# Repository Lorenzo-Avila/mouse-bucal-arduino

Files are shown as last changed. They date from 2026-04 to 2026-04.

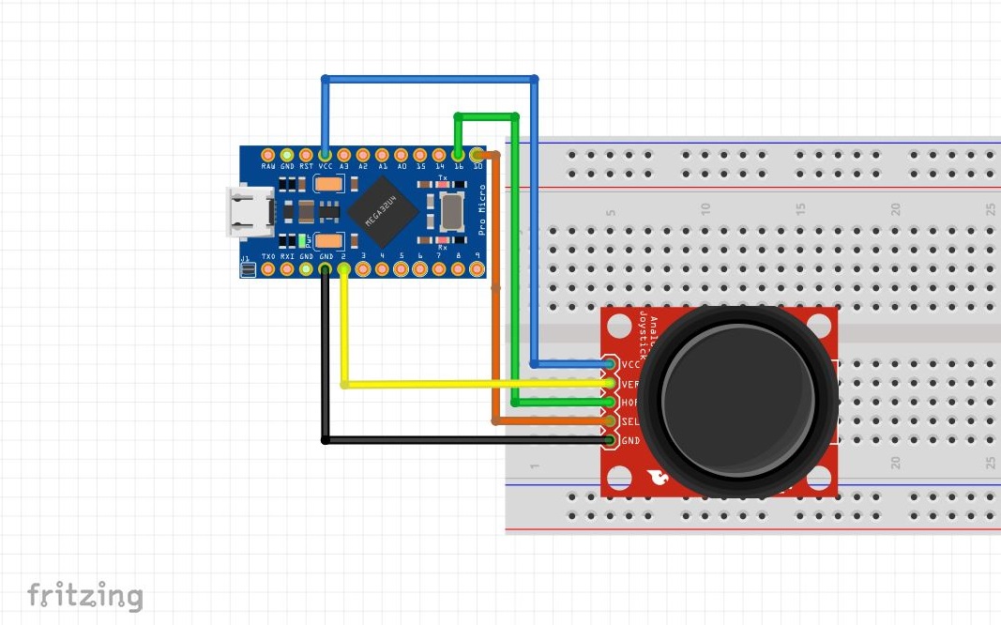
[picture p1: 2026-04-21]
hardware/Diagrama_de_Circuitos.JPG

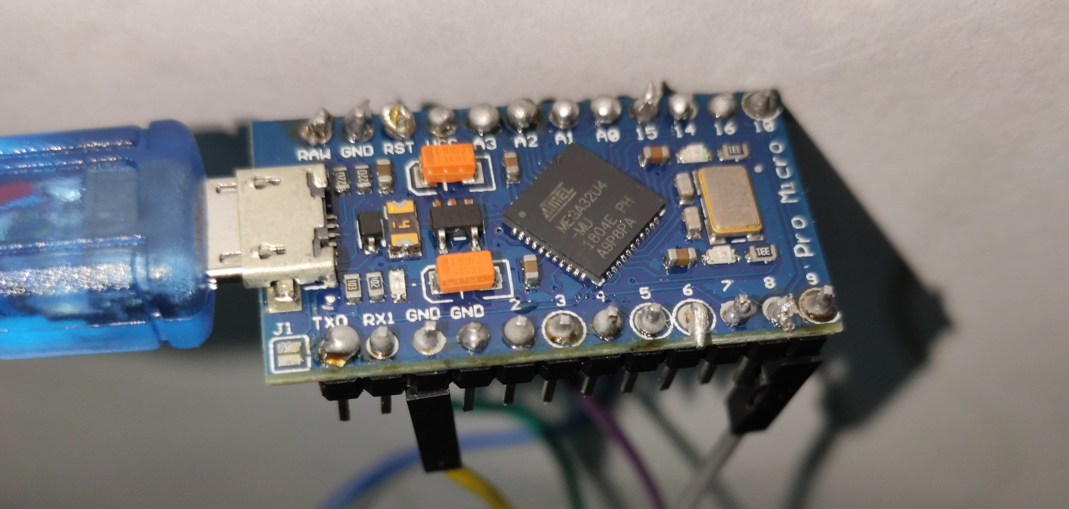
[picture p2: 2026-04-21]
fotos_prototipo/Ligacoes_2.jpg

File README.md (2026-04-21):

# 🖱️ Mouse Bucal — Tecnologia Assistiva com Arduino Pro Micro

> **TCC — Instituto Federal de Educação, Ciência e Tecnologia Farroupilha Campus São Borja — Técnico em Informática (2020)**  
> Dispositivo de interface humana (HID) que emula um mouse via joystick controlado pela boca, projetado para pessoas com deficiências motoras severas nos membros superiores.

---

## 📋 Sumário

- [Problema Resolvido](#-problema-resolvido)
- [Como Funciona](#-como-funciona)
- [Tecnologias e Componentes](#-tecnologias-e-componentes)
- [Estrutura do Repositório](#-estrutura-do-repositório)
- [Instalação e Montagem](#-instalação-e-montagem)
- [Configuração do Software](#-configuração-do-software)
- [Diagrama de Atores e Fluxo](#-diagrama-de-atores-e-fluxo)
- [Análise Técnica do Código](#-análise-técnica-do-código)
- [Modelo 3D](#-modelo-3d)
- [Sugestões de Melhorias](#-sugestões-de-melhorias)
- [Fundamentação Teórica](#-fundamentação-teórica)

---

## 🎯 Problema Resolvido

Pessoas com limitações motoras severas nos membros superiores como tetraplegia, distrofia muscular ou sequelas de AVC encontram barreiras significativas no uso de computadores convencionais. Este projeto oferece uma solução de **Tecnologia Assistiva (TA)** de baixo custo que permite controle completo do cursor por meio de movimentos da boca/cabeça, promovendo autonomia digital e inclusão social.

**Contexto:** A Declaração de Salamanca (1994) e as diretrizes brasileiras de inclusão exigem ferramentas adaptadas para que pessoas com deficiência possam participar plenamente de atividades educacionais e profissionais mediadas por computador.

---

## ⚙️ Como Funciona

```
[Usuário]
    │
    ▼ movimento da boca/mandíbula
[Joystick 3 eixos]  ──(A0, A2, D9)──►  [Arduino Pro Micro]
                                               │
                                         USB HID (nativo)
                                               │
                                               ▼
                                        [Computador — Driver-free]
                                        Cursor X/Y + Click esquerdo
```

1. O joystick é posicionado na boca do usuário via suporte impresso em 3D.  
2. Movimentos da mandíbula/língua deflectem o joystick nos eixos X e Y.  
3. O Arduino Pro Micro lê os valores analógicos (ADC 10-bit, 0–1023).  
4. A diferença do valor neutro (calibrado na inicialização) é mapeada em deslocamento do cursor.  
5. Pressionar o joystick (eixo Z) aciona o clique esquerdo do mouse.  
6. O computador reconhece o dispositivo automaticamente como mouse USB (sem drivers adicionais).

---

## 🔧 Tecnologias e Componentes

### Hardware

| Componente | Especificação | Função |
|---|---|---|
| **Arduino Pro Micro** | ATmega32U4, 5V/16MHz | MCU com USB HID nativo |
| **Módulo Joystick** | 3 eixos (X, Y, Z), potenciômetros 10kΩ | Sensor de movimento |
| **Cabo USB Micro-B** | Standard | Alimentação + dados |
| **Invólucro 3D** | PLA/ABS, STL binário (51.518 triângulos) | Suporte ergonômico bucal |
| **Parafusos/Fixadores** | M2/M3 | Montagem mecânica |

### Software / Ferramentas

| Ferramenta | Versão Recomendada | Uso |
|---|---|---|
| **Arduino IDE** | 2.x | Upload do firmware |
| **Biblioteca `Mouse.h`** | Built-in (Arduino AVR) | Emulação HID USB |
| **Fritzing** | 0.9.x | Esquemático do circuito (`.fzz`) |
| **Slicer 3D** (Cura/PrusaSlicer) | Qualquer | Impressão do modelo `.stl` |

---

## 📁 Estrutura do Repositório

| Pasta | Arquivo(s) | Descrição |
|---|---|---|
| `firmware/` | `Emulador_Mouse.ino` | Código principal — lógica do mouse HID |
| `hardware/` | `Joystick_and_arduino.fzz` | Esquemático completo no Fritzing |
| | `esquematico_prototipo.JPG` | Diagrama de conexões (imagem) |
| | `esquema_de_funcionamento.png` | Fluxo do sistema |
| | `Diagrama_de_Circuitos.JPG` | Foto do circuito montado |
| `3dmodels[](url)/` | `Modelo3d_projeto.stl` | Invólucro bucal — STL binário (~2,5 MB, 51.518 triângulos) |
| `docs/` | `Ata_de_Defesa_Final_do_Trabalho_de_Conclusão_de_Curso.docx` | Ata de Defesa Final do Trabalho de Conclusão de Curso |
| `Relatório_de_Trabalho_de_Conclusao_de_curso.docx` | Relatório técnico  referente ao Trabalho de Conclusão de Curso |
| | `Atores_do_Sistema.jpg` | Diagrama de atores do sistema |
| `fotos_prototipo/` | `impressao_bucal_1.jpg` · `impressao_bucal_2.jpg`  | Vistas externas da impressão do bucal protótipo finalizado |
| | `protitpo_finalizado_sem_involtorio.jpg` · `prototipo_finalizado_com_involtorio_visao_externa.jpg` | Comparação sem/com invólucro |
| | `prototipo_finalizado_com_involtorio_parte_interna.jpg` | Eletrônica interna montada |
| | `Ligacoes_1.jpg` · `Ligacoes_2.jpg` · `Ligacoes_3.jpg` | Fiação e conexões detalhadas |
| | `arduino_pro_micro.jpg` · `Joystick.jpg` | Componentes individuais |

**Como abrir cada tipo de arquivo:**

| Extensão | Ferramenta |
|---|---|
| `.ino` | Arduino IDE 2.x |
| `.fzz` | Fritzing 0.9.x |
| `.stl` | Cura / PrusaSlicer / Blender |
| `.docx` | Word / LibreOffice Writer |
| `.jpg` / `.png` | Qualquer visualizador de imagens |

---

## 🔨 Instalação e Montagem

### Pré-requisitos

- Arduino IDE 2.x instalado
- Impressora 3D (ou serviço de impressão) para o invólucro
- Filamento PLA (recomendado para contato bucal: **PETG food-safe** ou revestimento com verniz atóxico)

### Passo 1 — Impressão 3D

1. Abra o arquivo `3d-models/Modelo 3d TCC (1).stl` no seu slicer.
2. Configurações sugeridas:
   - Preenchimento: **30–40%** (honeycomb)
   - Altura de camada: **0.2mm**
   - Suportes: Ativados (verifique as abas de encaixe do joystick)
3. Imprima e lixe as bordas que terão contato com a boca.

### Passo 2 — Conexões Elétricas

| Pino Joystick | Pino Arduino Pro Micro |
|---|---|
| VCC | VCC (5V) |
| GND | GND |
| VRX (eixo horizontal) | A0 |
| VRY (eixo vertical) | A2 |
| SW (botão/click) | D9 |

> **Atenção:** O pino D9 usa `INPUT_PULLUP` interno — leitura `LOW` indica botão pressionado.

### Passo 3 — Upload do Firmware

1. Abra `firmware/Emulador_Mouse.ino` na Arduino IDE.
2. Selecione: **Ferramentas → Placa → Arduino AVR → Arduino Leonardo** (compatível com Pro Micro ATmega32U4).
3. Selecione a porta COM correta.
4. Clique em **Upload**.
5. Na primeira inicialização, mantenha o joystick na **posição neutra** por 1 segundo — o código calibra o ponto zero automaticamente.

### Passo 4 — Montagem Mecânica

1. Encaixe o módulo joystick no suporte impresso.
2. Direcione os cabos pelo canal interno do invólucro.
3. Prenda o Arduino Pro Micro no compartimento traseiro.
4. Conecte o cabo USB ao computador — nenhum driver adicional necessário.

---

## 💻 Configuração do Software

### Ajuste de Sensibilidade

No arquivo `.ino`, a constante `sensitivity` controla a velocidade do cursor:

```cpp
const int sensitivity = 200; // ← altere este valor
```

| Valor | Comportamento |
|---|---|
| `50–100` | Cursor **muito rápido** — para usuários com controle preciso |
| `200` | **Padrão** (configuração original) |
| `400–600` | Cursor **lento** — ideal para tremores ou movimentos involuntários |

---

## 📐 Diagrama de Atores e Fluxo

**Atores do Sistema:**

- **Usuário** — pessoa com deficiência motora que utiliza o dispositivo bucal
- **Supervisor** — responsável pela instalação, posicionamento e verificação do protótipo

**Fluxo de Operação:**

```
Supervisor conecta USB → Sistema inicializa (1s calibração)
        │
        ├─ Sensores OK? ──NÃO──► Sistema reinicia
        │
        SIM
        │
        ▼
Monitoramento contínuo do joystick
        │
        ├─ Movimento eixo X → Mouse.move(Δx, 0, 0)
        ├─ Movimento eixo Y → Mouse.move(0, Δy, 0)
        └─ Botão pressionado → Mouse.press/release (LEFT)
```

---

## 🔬 Análise Técnica do Código

### Lógica Central

```cpp
// Leitura diferencial — desconta o ponto zero calibrado
vertValue = analogRead(vertPin) - vertZero;
horzValue = analogRead(horzPin) - horzZero;

// Movimento proporcional dividido pela sensibilidade
if (vertValue != 0) Mouse.move(0, vertValue / sensitivity, 0);
if (horzValue != 0) Mouse.move(horzValue / sensitivity, 0, 0);

// Clique com debounce via flag
if (digitalRead(selPin) == 0 && !mouseClickFlag) {
    mouseClickFlag = 1;
    Mouse.press(MOUSE_LEFT);
} else if (digitalRead(selPin) && mouseClickFlag) {
    mouseClickFlag = 0;
    Mouse.release(MOUSE_LEFT);
}
```

## 🖨️ Modelo 3D

- **Formato:** STL Binário
- **Complexidade:** 51.518 triângulos
- **Tamanho:** ~2,5 MB
- **Finalidade:** Invólucro ergonômico que acopla o módulo joystick em posição bucal
- **Integração com eletrônica:** Cavidades internas para passagem de cabos; compartimento traseiro para o Arduino Pro Micro; encaixe frontal para o joystick na posição bocal

> ⚠️ **Recomendação de material:** Para uso em contato com a boca, imprimir em **PETG food-safe** ou aplicar **revestimento atóxico** (verniz epóxi alimentar) sobre PLA.

### 🟢 Evoluções Futuras

**8. Sopro/Sucção como Botão** — sensor de pressão (BMP280) para ação de clique sem usar o joystick como botão

**9. Modo de Acessibilidade Configurável** — potenciômetro externo para ajuste de sensibilidade em tempo real sem reprogramar

**10. BLE/Wireless** — substituir Arduino Pro Micro por **Seeed XIAO nRF52840** para versão sem fio (Bluetooth HID)

**11. Controle por Inclinação (IMU)** — adicionar MPU-6050 para controle por movimento de cabeça, dispensando o joystick

---

## 📚 Fundamentação Teórica

- **Declaração de Salamanca (UNESCO, 1994):** Estabelece diretrizes mundiais para educação inclusiva, motivando o desenvolvimento de ferramentas assistivas.
- **Tecnologia Assistiva (TA):** Campo interdisciplinar que cria produtos e serviços para promover funcionalidade e autonomia de pessoas com deficiência.
- **USB HID (Human Interface Device):** Protocolo USB que permite que microcontroladores se comuniquem com computadores como periféricos de entrada sem drivers adicionais — viabilizado pelo chip ATmega32U4 do Arduino Pro Micro.
- **ADC (Analog-to-Digital Converter):** Converte o sinal analógico dos potenciômetros do joystick (0–5V) em valores digitais de 10 bits (0–1023), mapeados em deslocamento do cursor.

---

## 📄 Licença

Projeto acadêmico de código aberto. Uso livre para fins educacionais e de pesquisa em Tecnologia Assistiva.

---

*Desenvolvido como Trabalho de Conclusão de Curso — Técnico em Informática, 2020.*

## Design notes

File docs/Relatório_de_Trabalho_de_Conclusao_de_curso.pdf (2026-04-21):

INSTITUTO FEDERAL DE EDUCAÇÃO, CIÊNCIA E TECNOLOGIA FARROUPILHA CAMPUS SÃO BORJA
CURSO TÉCNICO EM INFORMÁTICA INTEGRADO

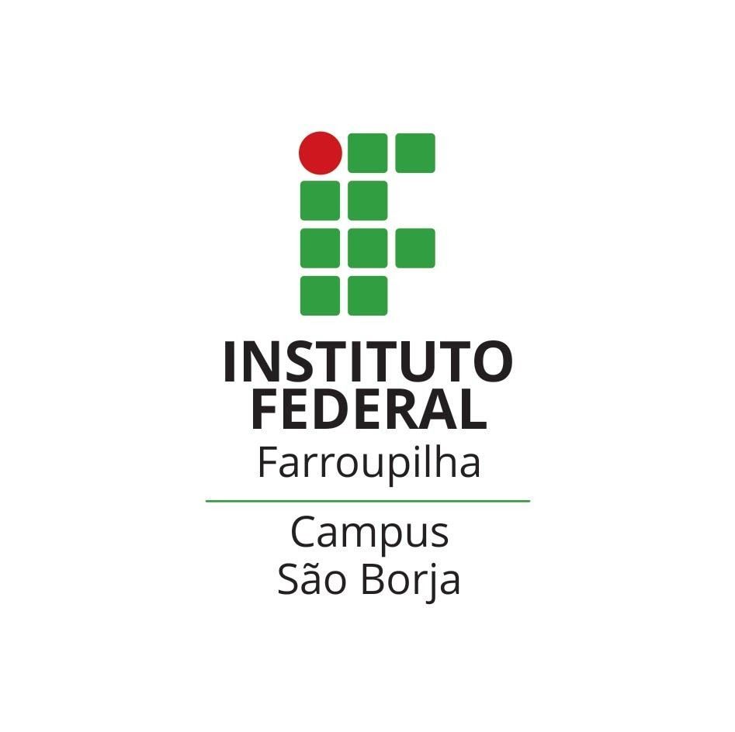
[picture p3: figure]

LORENZO DE ÁVILA CARPES

INTERFACE DE MOUSE PARA DEFICIENTES MOTORES

São Borja/RS
2020/2

LORENZO DE ÁVILA CARPES

INTERFACE DE MOUSE PARA DEFICIENTES MOTORES

Relatório referente ao Trabalho de Conclusão de Curso, apresentado como requisito para obtenção do título de Técnico em Informática, do Instituto Federal de Educação, Ciência e Tecnologia Farroupilha Campus São Borja.

Orientador(a): Rafael Ogayar Gomes

São Borja/RS
2020/2

LORENZO DE ÁVILA CARPES

INTERFACE DE MOUSE PARA DEFICIENTES MOTORES

Relatório referente ao Trabalho de Conclusão de Curso, apresentado como requisito para obtenção do título de Técnico em Informática, do Instituto Federal de Educação, Ciência e Tecnologia Farroupilha Campus São Borja.

Aprovado em 29 de Janeiro de 2021.

BANCA EXAMINADORA

Rafael Ogayar Gomes
[Professor Orientador]

Luciéli Tolfo Beque Guerra [Professor Banca]

Claiton Marques Correa
[Professor Banca]

“Nenhum esforço faz sentido, se você não acredita em si mesmo”

Maito Gai

LISTA DE ILUSTRAÇÕES

Figura 1: Diagrama de Circuitos | 12
Figura 2: Arduino Pro Micro ATmega32u4 Micro USB | 13
Figura 3: Joystick Arduino 3 Eixos | 14
Figura 4: Esquema de Funcionamento | 15
Figura 6: Teste realizado com a interface. | 16
Figura 7: Teste realizado com a interface. | 17
Figura 7: Componentes protótipo. | 18
Figura 8: Ligações com o joystick | 19
Figura 9: Ligações com o Arduino Pro Micro | 20
Figura 10: Ligações com o Arduino Pro Micro | 20
Figura 11: Bucal impresso em 3D | 21
Figura 12: Bucal impresso em 3D | 22
Figura 14: Protótipo finalizado | 23
Figura 15: Protótipo finalizado | 24

LISTA DE TABELAS

Tabela 1: Metodologia | 11

7

SUMÁRIO

1 INTRODUÇÃO | 8
2 OBJETIVOS | 8
2.1.OBJETIVO GERAL | 8
2.2.OBJETIVOS ESPECÍFICOS | 9

### 3 METODOLOGIA

9

4 DESENVOLVIMENTO DE SISTEMA | 10
4.1.REQUISITOS DO SISTEMA | 10
4.1.1 Convenções, termos e abreviações | 10
4.1.2 Atores do Sistema | 10
4.1.3 Requisitos Funcionais | 11
4.1.4 Requisitos Não-Funcionais | 11
4.2 DIAGRAMA DE CIRCUITOS | 12
4.3 HARDWARE UTILIZADO | 13
4.4 ESQUEMA DE FUNCIONAMENTO | 15
4.5 TESTES REALIZADOS | 15
4.6 PROJETO DESENVOLVIDO | 17
5 CONSIDERAÇÕES FINAIS | 24
6 REFERÊNCIAS | 24

### 1 INTRODUÇÃO

No ano de 1994, em Salamanca, na Espanha, em meio a Conferência Mundial sobre Educação Especial foi estabelecido a Declaração de Salamanca, cujo o enfoque foram diretrizes básicas para a formulação e reforma de políticas e sistemas educacionais de acordo com o movimento de inclusão social, de forma com que o sistema regular de ensino atenda a especificidade de cada indivíduo, especialmente daqueles portadores de algum tipo de deficiência (MENEZES, 2001).
Para que as ações de inclusão social sejam concretizadas, se faz necessário a criação de ferramentas e tecnologias capazes de auxiliar portadores de necessidades especiais a realizarem atividades de suma importância para o desenvolvimento da educação. Diante disso, foi desenvolvida uma interface de mouse focada em auxiliar pessoas que possuem limitação de movimento, a fim de proporcionar meios para que possam se tornar mais independentes no uso de computadores.
O presente trabalho teve como objetivo geral desenvolver uma Tecnologia Assistiva (TA), cuja função é auxiliar alunos que convivem com alguma deficiência motora que os impossibilite de utilizar das tecnologias convencionais de mouses no manuseio de computadores. A interface se faz viável devido a sua praticidade e baixo custo em comparação às demais ferramentas disponíveis no mercado.
Para a realização deste projeto as seguintes ferramentas foram utilizadas: Arduino IDE, para codificação; Fritzing, para a elaboração do circuito integrado; Astah Community; para criação do esquema de funcionamento; Tinkercad para desenvolvimento do modelo 3D. A seguir serão apresentadas as seções deste trabalho, por começo temos os objetivos gerais e específicos do projeto, acompanhado pela metodologia, que expõe o processo de pesquisa para o desenvolvimento das atividades, logo após desenvolvimento do sistema e considerações finais.

### 2 OBJETIVOS

2.1. OBJETIVO GERAL

Desenvolver uma Tecnologia Assistiva que auxilie alunos portadores de deficiências motoras no uso de computadores.

2.2. OBJETIVOS ESPECÍFICOS
1. Realizar estudo sobre hardwares microcontrolados;
2. Realizar estudo sobre sensores e atuadores;
3. Referencial teórico sobre deficiências cognitivas;
4. Desenvolvimento de Circuito integrado;
5. Realização de casos de testes;

### 3 METODOLOGIA

A tabela a seguir (Tabela 1) apresenta os procedimentos metodológicos deste trabalho de conclusão de curso.

Tabela 1: Metodologia
Objetivo Específico | Ação
1. Realizar estudo sobre hardwares microcontrolados | Efetuar pesquisas em sites web e artigos relacionados a hardwares microcontrolados a fim de ter um ensino mais aprofundado no assunto.
2. Realizar estudo sobre sensores e atuadores | Efetuar pesquisas em sites web e artigo a respeito de sensores e atuadores a fim de ter um ensino mais aprofundado no assunto.
3. Referencial teórico sobre deficiências cognitivas | Coletar dados sobre deficiências cognitivas, para constatar as necessidades dos usuários.
4. Desenvolvimento de Circuito integrado | Desenvolver uma Tecnologia Assistiva de baixo de custo de produção, utilizando os seguintes materiais: ● Arduino Pro Micro com um conector USB e ATmega32u4 ● Módulo Joystick ● Jumper Protoboard Macho-Fêmea
5. Realização de casos de testes | Fazer testes de validação e verificação através da inserção de dados.

### 4 DESENVOLVIMENTO DE SISTEMA

Esta seção do trabalho apresenta as etapas do processo de desenvolvimento do sistema proposto por esse trabalho de conclusão de curso, que está dividida em partes: documentação de requisitos do sistema, diagrama de circuito, a descrição do circuito e a descrição do hardware e de suas funcionalidades, o esquema de funcionamento, bem como documentação e registros fotográficos do projeto desenvolvido.

4.1. REQUISITOS DO SISTEMA

Esta seção especifica os requisitos do sistema Interface de mouse para deficientes motores.

### 4.1.1 Convenções, termos e abreviações

Por convenção, a referência a requisitos é feita através do nome da subseção onde eles estão descritos, seguidos do identificador do requisito, de acordo com a especificação a seguir:
[identificador do requisito – nome do requisito] Por exemplo, o requisito funcional RF01 – Acionar sensor. Já o requisito não-funcional NF008 - Confiabilidade. Os requisitos devem ser identificados com um identificador único. A numeração inicia com o identificador [RF001] ou [NF001] e prossegue sendo incrementada à medida que forem surgindo novos requisitos.

### 4.1.2 Atores do Sistema

O sistema apresenta dois atores diferenciados pelos seus respectivos “privilégios” sob o sistema.

- Usuário: Toda pessoa externa à Interface. A pessoa do usuário se concretiza com o ato da utilização da tecnologia assistiva.
- Supervisor: Pessoa que é responsável pela verificação do andamento do protótipo, sua instalação e funcionamento.

### 4.1.3 Requisitos Funcionais

Tomando por base o contexto do sistema, foram identificados os seguintes requisitos funcionais:

[RF001] Sensoriamento

Descrição do RF: O sistema verifica junto ao sensor de joystick qual a posição em x e y.

[RF002] Verificar sensor

Descrição do RF: O Arduino verifica o sensor e assim realiza a movimentação do mouse.

RF003] Movimentar mouse

Descrição do RF: Este requisito permite que o usuário movimente o cursor do mouse como desejar.

[RF004] Clicar com o mouse

Descrição do RF: O Arduino identifica que o joystick foi pressionado realizando assim a ação de clicar.

### 4.1.4 Requisitos Não-Funcionais

[NF001] Usabilidade

A interface deve ser de uso simples, para que os usuários possam utilizá-la com facilidade durante a realização de alguma tarefa específica e importante.

Prioridade: | ■ Essencial | ◻ Importante | ◻ Desejável
Prioridade: | ■ Essencial | ◻ Importante | ◻ Desejável
Prioridade: | ■ Essencial | ◻ Importante | ◻ Desejável
Prioridade: | ■ Essencial | ◻ Importante | ◻ Desejável

[NF002] Desempenho

Embora não seja um requisito essencial ao sistema, deve ser considerada por corresponder a um fator de qualidade da ferramenta.

[NF003] Confortabilidade

Por ser uma tecnologia assistiva que pretende exercer as mesmas funções de um mouse convencional, o usuário deve se sentir confortável usando a ferramenta. De maneira em que o mesmo não sinta nenhum incômodo durante a utilização do projeto.

4.2 DIAGRAMA DE CIRCUITOS

A interface funciona da seguinte maneira, o arduino monitora constantemente os sensores do joystick e caso detecte algum movimento envia as informações via porta USB para o computador realizando a movimentação do cursor em X e Y correspondentes, conforme a Figura 1.

Figura 1: Diagrama de Circuitos

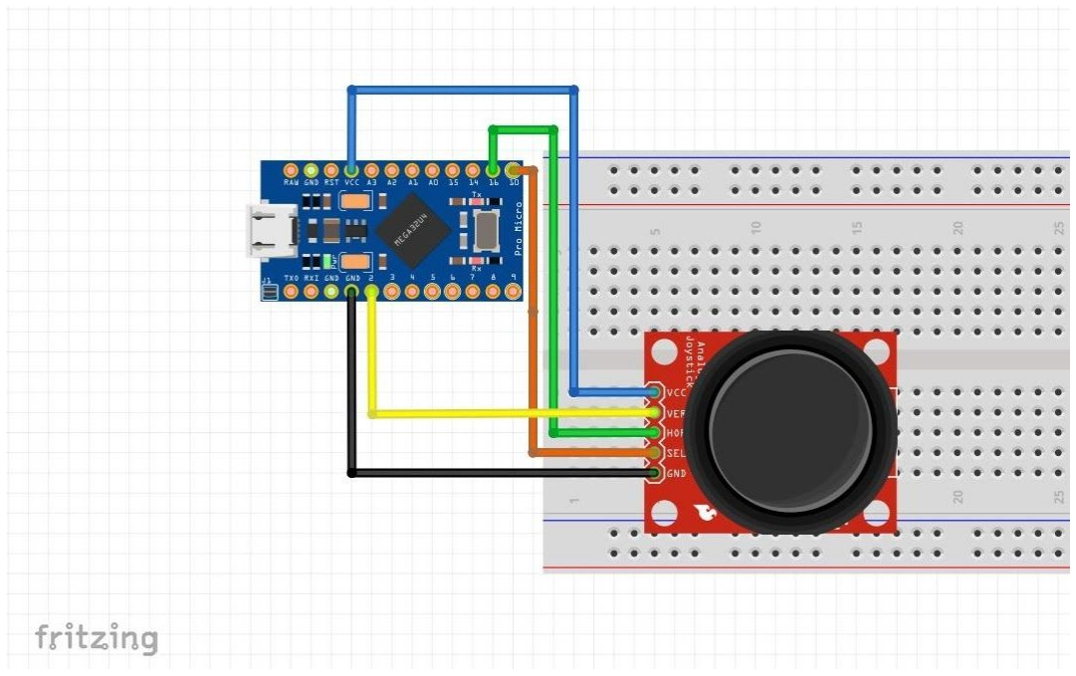
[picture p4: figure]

Fonte: Autoria própria

4.3 HARDWARE UTILIZADO

O hardware a ser utilizado durante a montagem da tecnologia assistiva, consiste em um Arduino Pro Micro ATmega32u4 Micro USB, representado na Figura 2. Esta placa de desenvolvimento utiliza o microcontrolador ATMega32U4, sendo amplamente empregada em projetos em que é necessário potência e velocidade de processamento. Comunica-se com o computador através porta micro-usb e pode ser programada utilizando-se a IDE do Arduino (HUINFINITO, 2018).
Por conta de suas características este microcontrolador pode funcionar como um dispositivo HID, emulando um mouse ou um teclado, diante disso este hardware se totalmente viável para o desenvolvimento do presente trabalho.

Figura 2: Arduino Pro Micro ATmega32u4 Micro USB

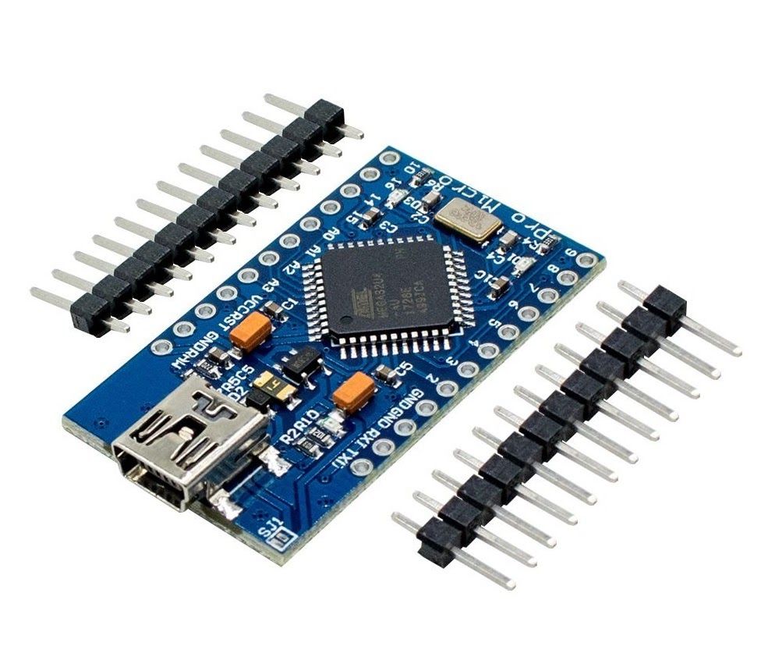
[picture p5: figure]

Fonte: https://www.filipeflop.com

Além da placa microcontroladora, será implementado um módulo de joystick 3 eixos, representado na Figura 3. Este joystick tem seu princípio de funcionamento através do controle de 2 potenciômetros e um botão. Duas das entradas dos potenciômetros referem-se aos eixos X e Y, sendo que o botão quando pressionado refere-se ao eixo Z. Logo este Joystick contém o total de três interfaces de entradas que são utilizadas para conectar ao eixo X, Y e Z (FLIFLOP, 2018).
Este módulo poderá ser modificado a fim de atender as necessidades específicas dos usuários.

Figura 3: Joystick Arduino 3 Eixos

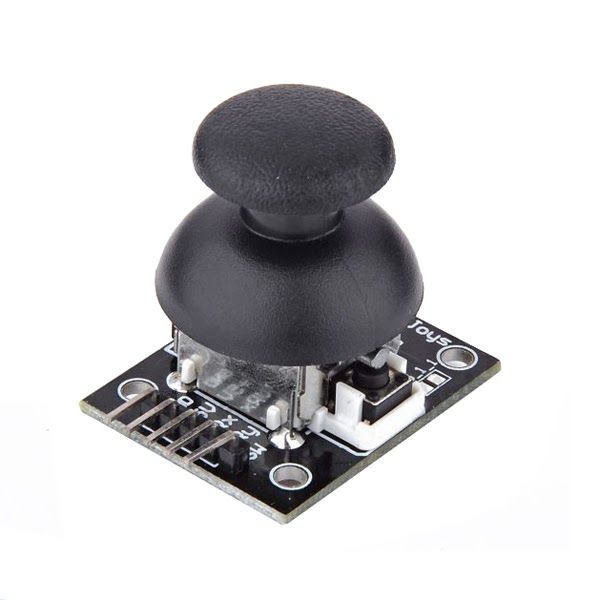
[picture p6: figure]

Fonte: https://www.filipeflop.com

4.4 ESQUEMA DE FUNCIONAMENTO

Conforme o diagrama abaixo (Figura 4), o supervisor liga o Arduino, conectando-o ao computador através da porta USB, e em seguida posiciona o usuário da melhor maneira para a utilização da tecnologia assistiva. Quando conectado ao computador o microcontrolador verificará os sensores podendo realizar duas ações distintas. Caso os sensores não estejam funcionando o sistema será reiniciado, por outro lado se os sensores estiverem funcionando sem nenhum problema o sistema será iniciado. A partir do momento em que o sistema é iniciado o Arduino irá monitorar os sensores constantemente e caso detecte algum movimento irá posicionar o cursor do mouse em X e Y correspondentes ao movimento realizado.

Figura 4: Esquema de Funcionamento

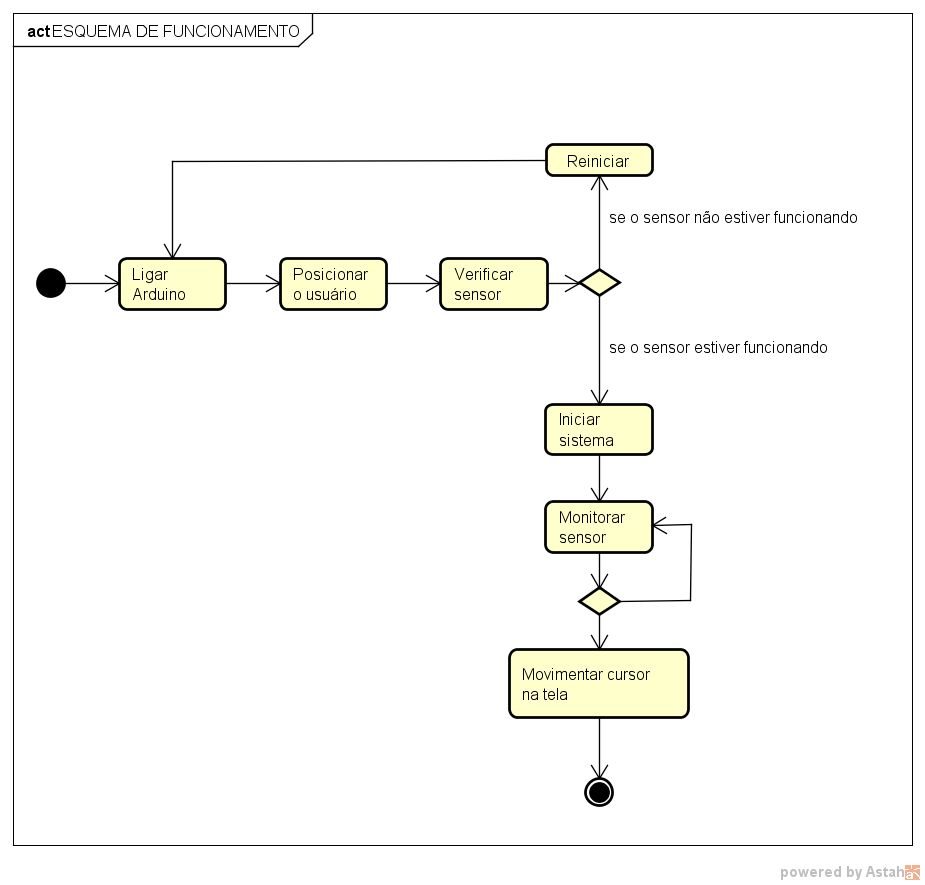
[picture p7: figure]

Fonte: Autoria própria

4.5 TESTES REALIZADOS

A fim de realizar a validação e verificação da interface foram realizados testes através da utilização da ferramenta, como é possível identificar nas Figura 6 e 7 a tecnologia assistiva foi empregada para navegação por artigos, onde se mostrou totalmente viável.

Por meio desta prática, foi possível constatar que a interface funciona de maneira satisfatória e não apresenta erros, cumprindo todos os requisitos anteriormente citados na seção 4.1 que apresenta os requisitos do sistema.

Figura 6: Teste realizado com a interface.

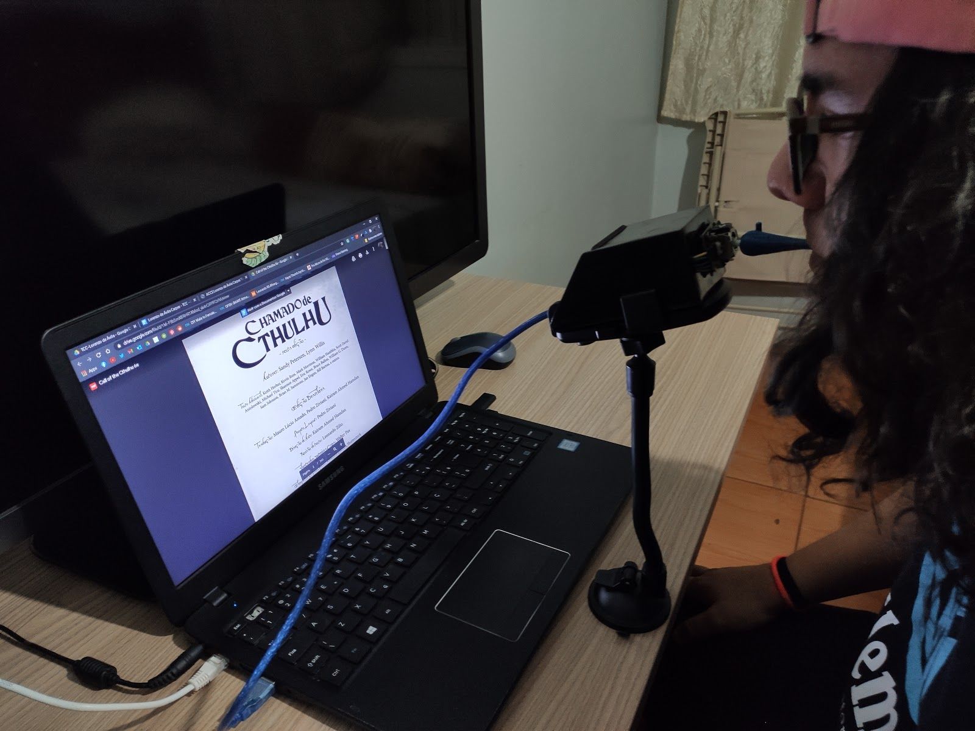
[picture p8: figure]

Fonte: Autoria própria

Figura 7: Teste realizado com a interface.

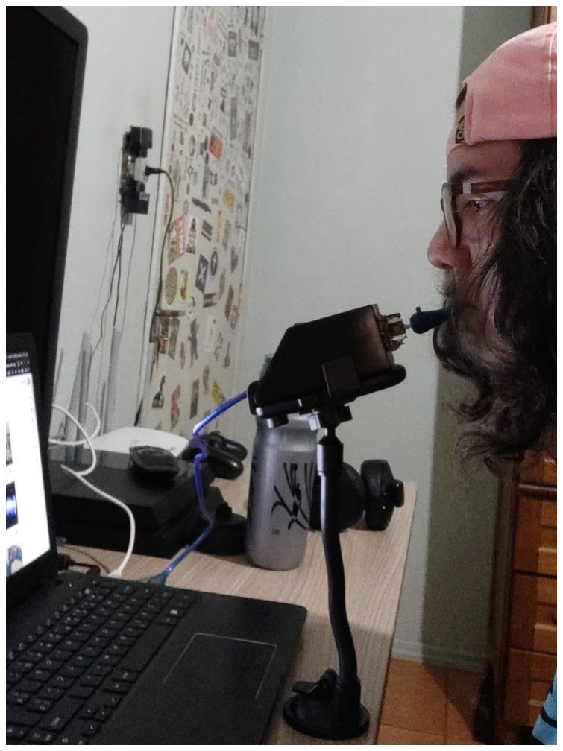
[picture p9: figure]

Fonte: Autoria própria

4.6 PROJETO DESENVOLVIDO

Esta seção apresenta o desenvolvimento do projeto. A Figura 7 exibe os componentes do protótipo, Arduino Pro Micro e módulo de Joystick, conectados entre si por meio de Jumpers Macho/Fêmea.

Figura 7: Componentes protótipo.

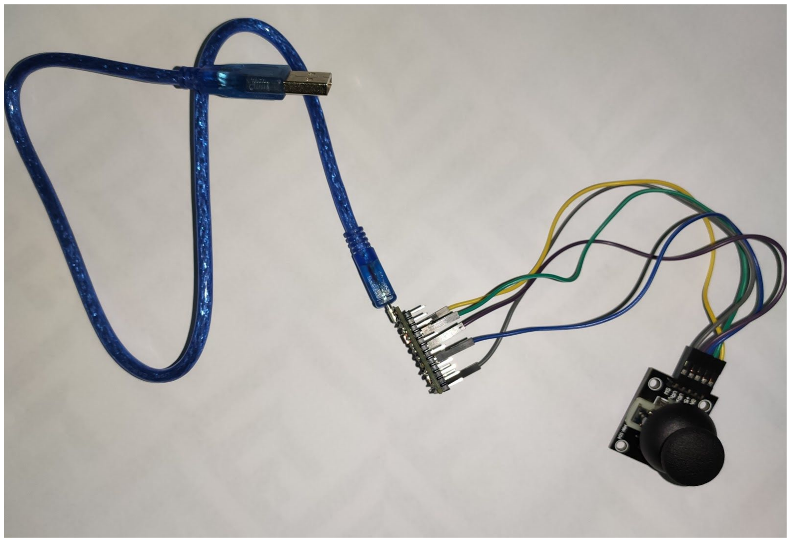
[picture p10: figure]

Fonte: Autoria própria

A Figura 8 apresenta as ligações do Joystick por meio dos Jumpers, da seguinte maneira: amarelo no GND, verde em 5V, azul na saída analógica do eixo X, roxo na saída analógica do eixo Y e cinza na saída digital do eixo Z (switch).

Figura 8: Ligações com o joystick

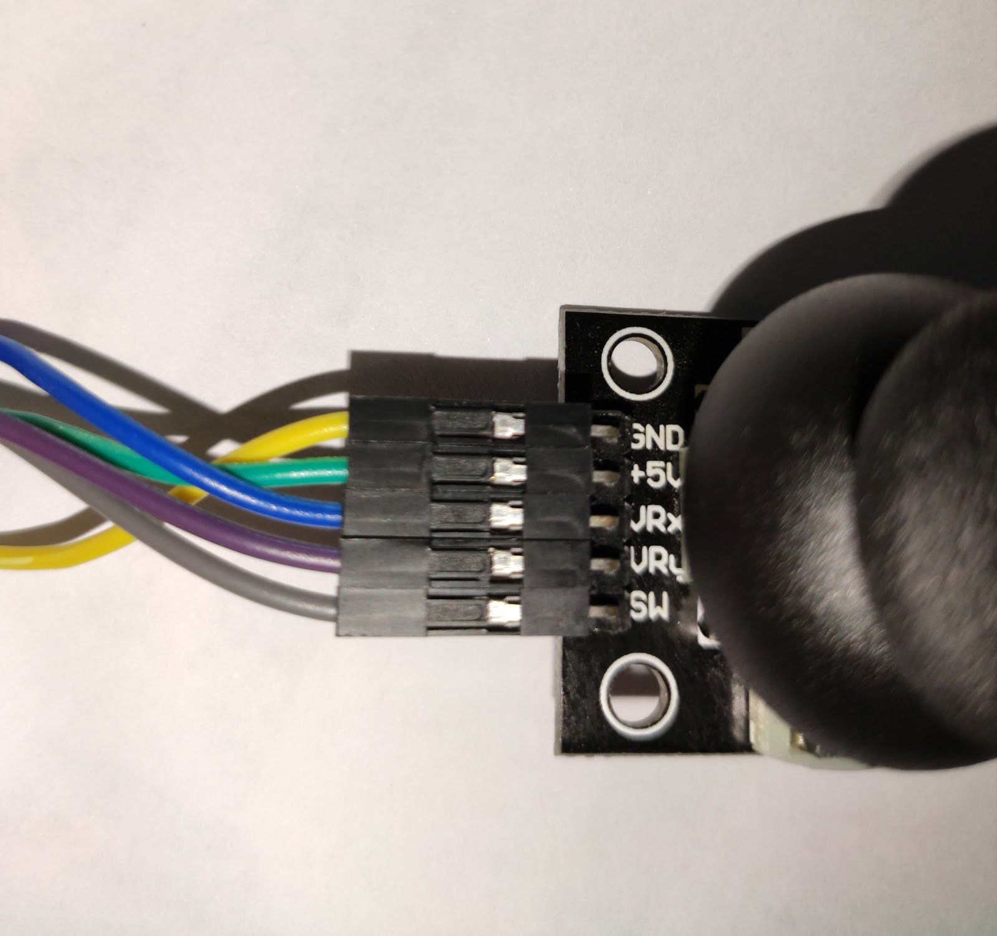
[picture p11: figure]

Fonte: Autoria própria

As Figuras 9 e 10 apresentam as ligações do Joystick com o Arduino, da seguinte maneira: GND do módulo conectado ao GND do microcontrolador, 5V ligado ao VCC, VRy ligado ao pino analógico A2, VRx ligado ao pino análogico A0 e SW concetado ao pino digital 9.

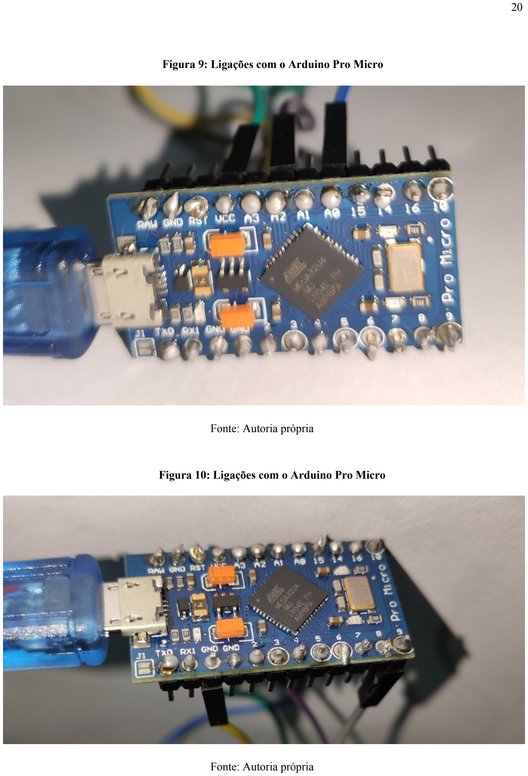
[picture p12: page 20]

Figura 9: Ligações com o Arduino Pro Micro

Fonte: Autoria própria

Figura 10: Ligações com o Arduino Pro Micro

Fonte: Autoria própria

As Figuras 11 e 12 exibem o processo de impressão do bucal da interface assistiva, este foi criado com o objetivo de melhorar a confortabilidade da ferramenta, de maneira que o usuário não sinta nenhum incômodo durante a utilização do projeto.

Figura 11: Bucal impresso em 3D

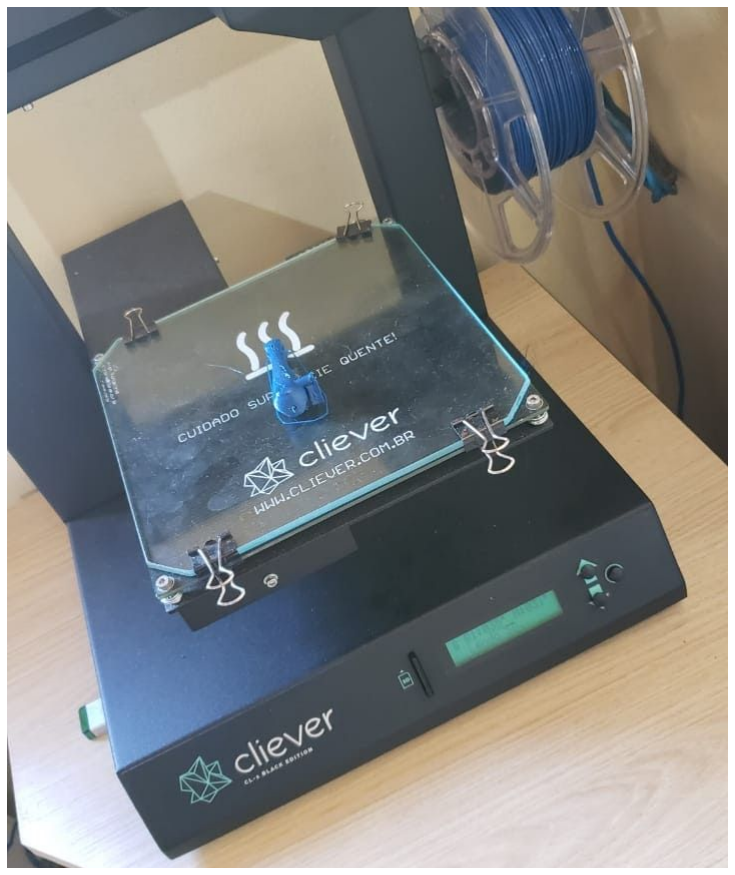
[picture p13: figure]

Fonte: autoria própria

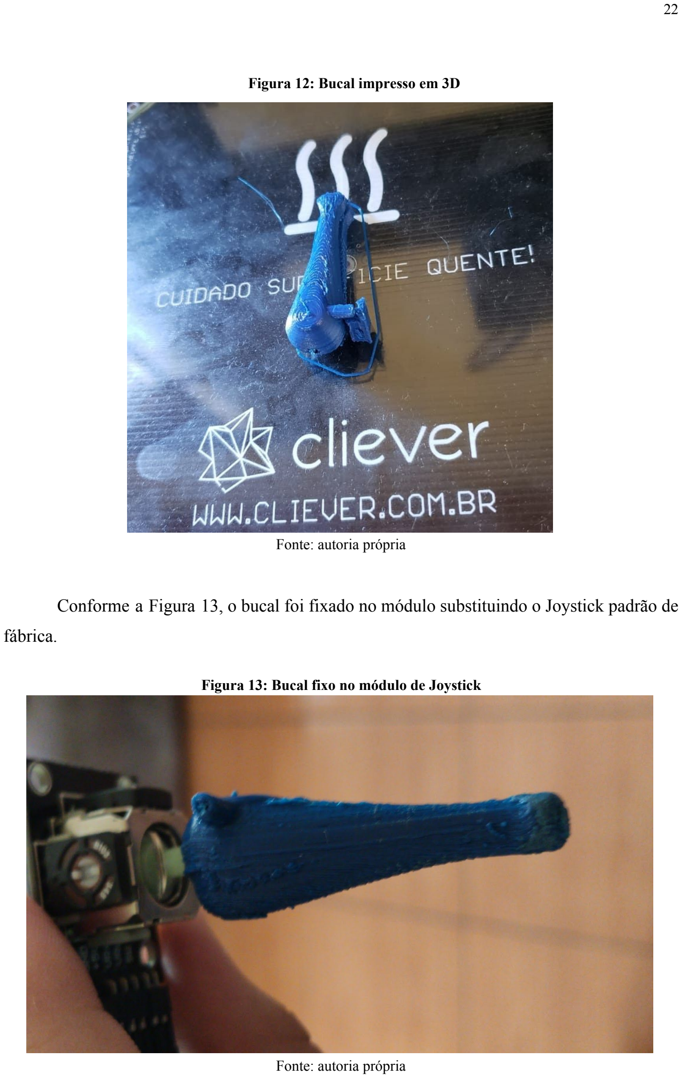
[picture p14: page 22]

Figura 12: Bucal impresso em 3D

Fonte: autoria própria

Conforme a Figura 13, o bucal foi fixado no módulo substituindo o Joystick padrão de fábrica.

Figura 13: Bucal fixo no módulo de Joystick

Fonte: autoria própria

As Figuras 14 e 15 apresentam o protótipo final, nelas é possível identificar os componentes da ferramenta fixados em um envoltório criado justamente para abrigar o Microcontrolador e fixar o módulo de Joystick possibilitando o uso da Tecnologia Assistiva por parte do usuário. Além disso, é nítida a presença de um braço articulável preso à mesa, cuja função é dar sustentação a interface e mantê-la elevada na altura da boca, possibilitando assim a utilização do mouse.

Figura 14: Protótipo finalizado

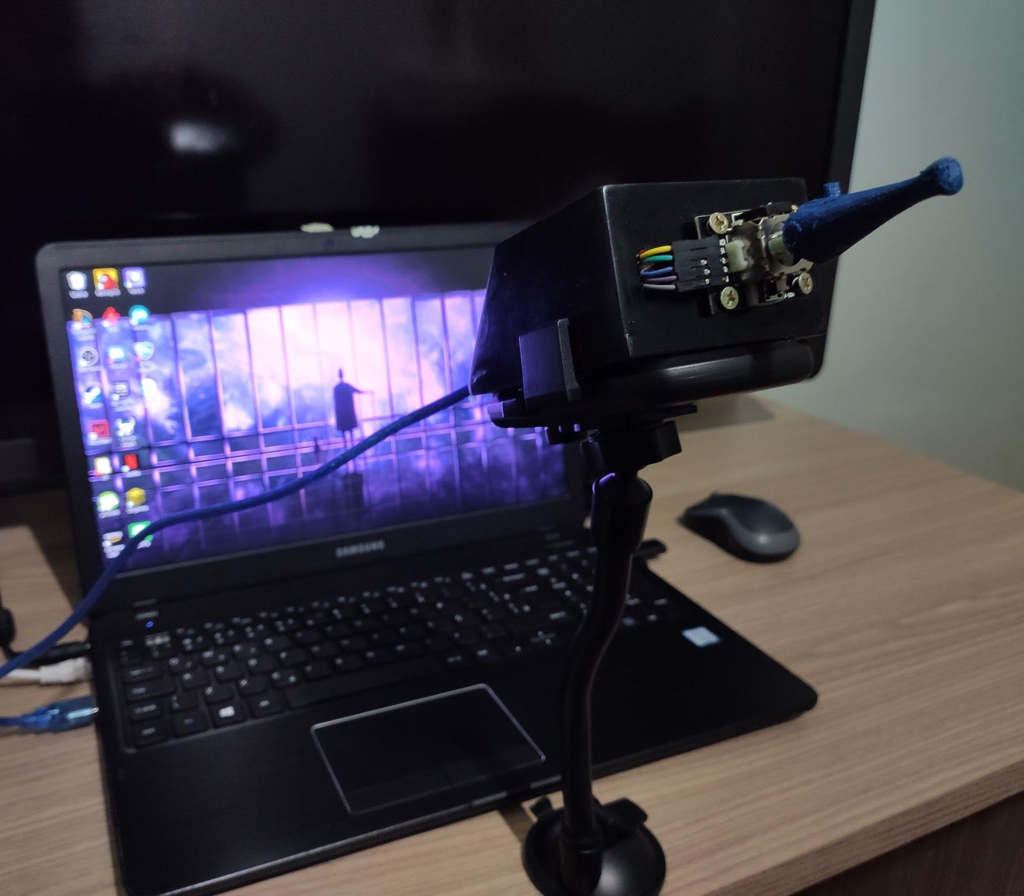
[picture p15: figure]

Fonte: autoria própria

Figura 15: Protótipo finalizado

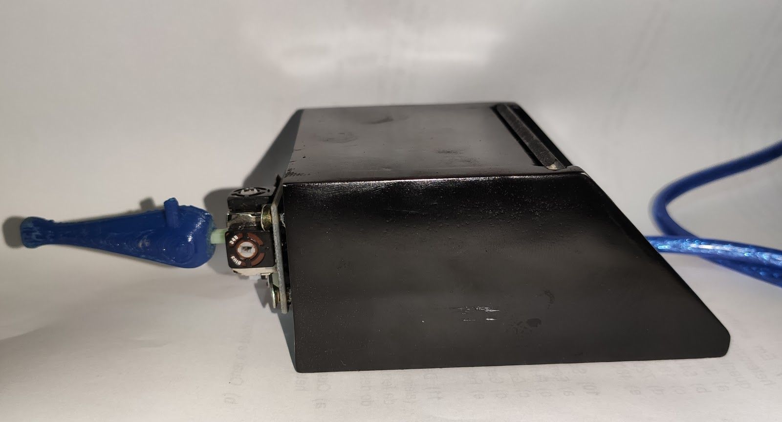
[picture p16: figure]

Fonte: autoria própria

### 5 CONSIDERAÇÕES FINAIS

Este relatório de trabalho de Conclusão de Curso (TCC), do Curso Técnico em Informática, teve como objetivo desenvolver uma interface de mouse acessível para auxiliar na independência de alunos com deficiência motora, de maneira que, proporcione a estes uma interação mais dinâmica com a tecnologia.
Espera-se que com uso desta ferramenta, indivíduos portadores de necessidades especiais possam usufruir de computadores sem a necessidade do auxílio de terceiros, gerando assim uma maior acessibilidade, além de facilitar o processo de aprendizagem para tutores e educandos.
Para trabalhos futuros poderá ser adicionado novas funcionalidades na interface, como a implementação de um microfone, a fim de possibilitar a pesquisa por voz, facilitando assim o uso de plataformas de pesquisa, com o objetivo auxiliar o usuário em possíveis buscas acadêmicas.

### 6 REFERÊNCIAS

MENEZES, E. T. D. Declaração de Salamanca. educabrasil, 2001. Disponível em: <https://www.educabrasil.com.br/declaracao-de-salamanca/>. Acesso em: 24 abr 2020.

JOYSTICK | ARDUINO | 3 | EIXOS. | Flipflop, | 2019. | Disponível | em:
https://www.filipeflop.com/produto/joystick-arduino-3-eixos/. Acesso em: 2 do set 2020.

ARDUINO PRO MICRO ATMEGA32U4. Huinfinito, 2018. Disponível em: https://www.huinfinito.com.br/arduino/1340-arduino-pro-micro-atmega32u4-5v16mhz.html. Acesso em: 4 do set 2020.

MONK, Simon. Programação com Arduino: Começando com Sketches. 2º edição. Local de publicação: Bookman, 20 julho 2017.

TEIXEIRA, Luzimar. Deficiência física: Definição, classificação, causas e características.
2010. | Disponível | em:
<http://www.luzimarteixeira.com.br/wp-content/uploads/2010/05/definicao-e-classificacao-da -deficiencia-fisica.pdf>. Acesso em: 24, abr 2020.

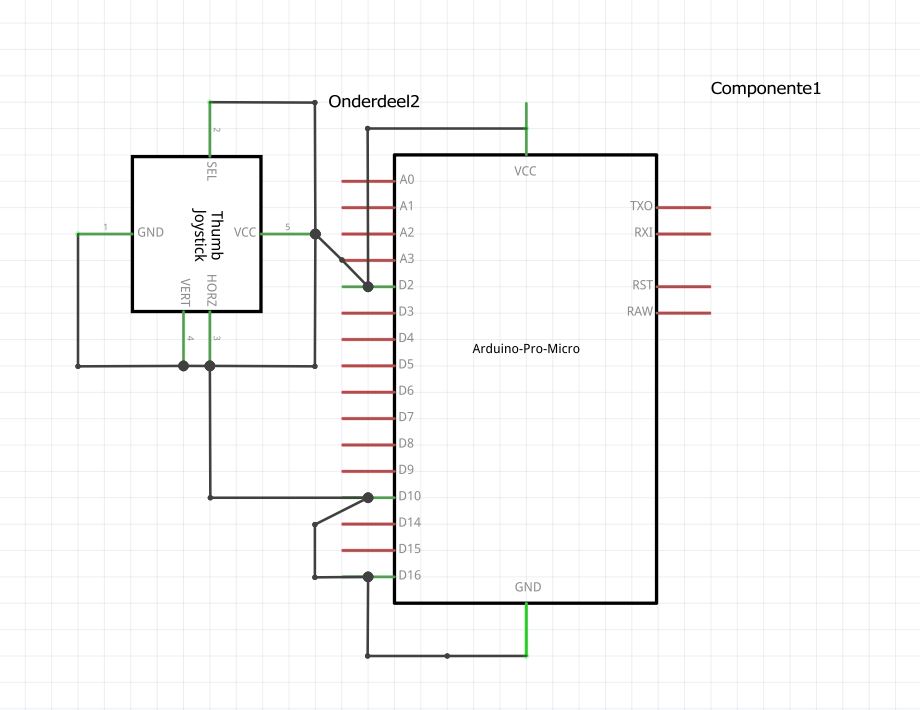
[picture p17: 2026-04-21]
hardware/esquematico_prototipo.JPG

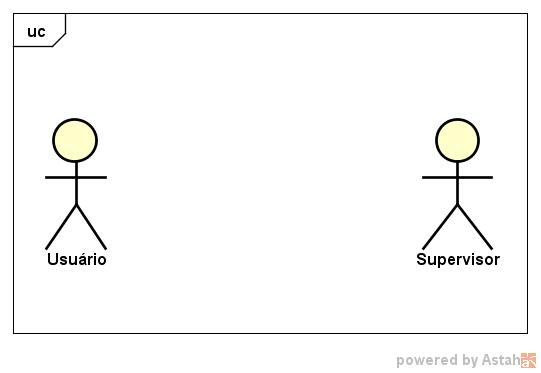
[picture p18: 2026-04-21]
docs/Atores_do_Sistema.jpg

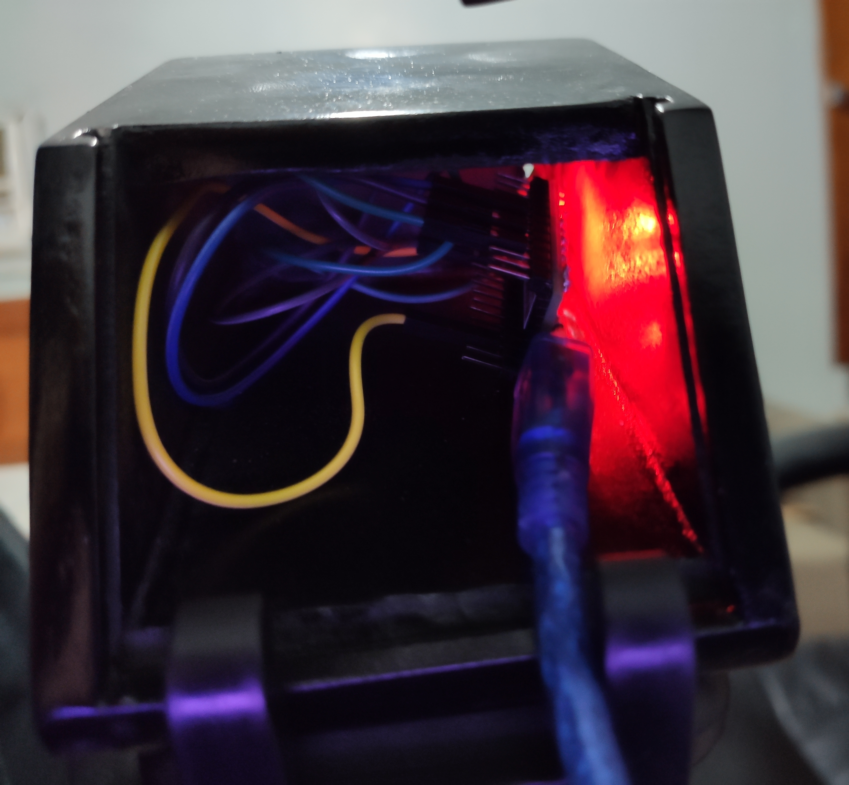
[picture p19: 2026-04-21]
fotos_prototipo/prototipo_finalizado_com_involtorio_parte_interna.jpg

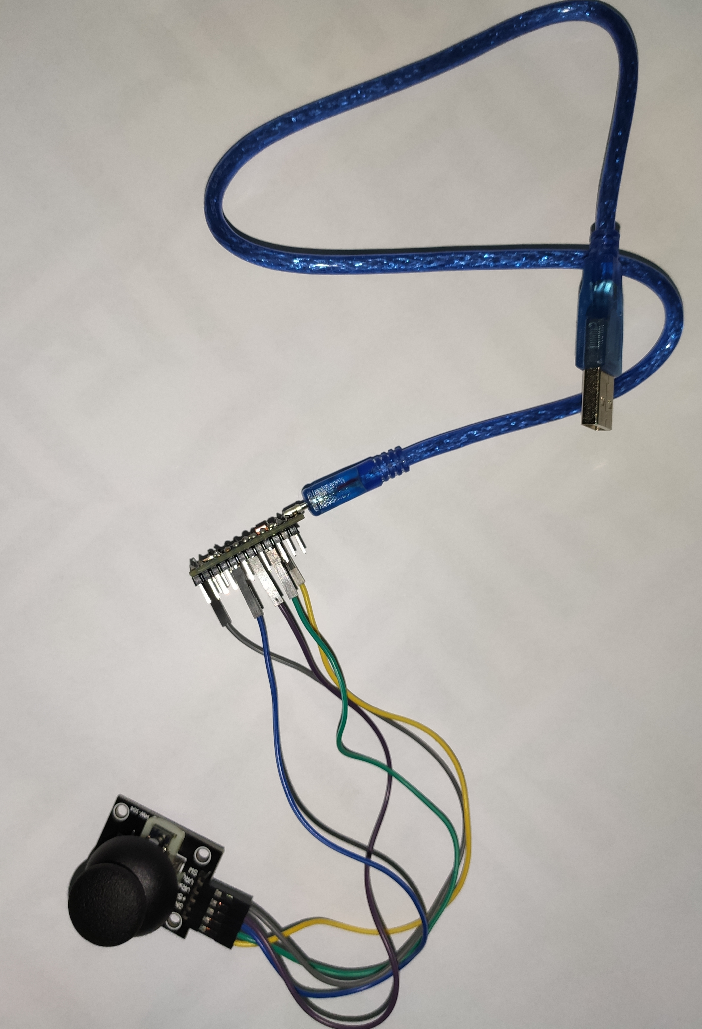
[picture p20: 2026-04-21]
fotos_prototipo/protitpo_finalizado_sem_involtorio.jpg

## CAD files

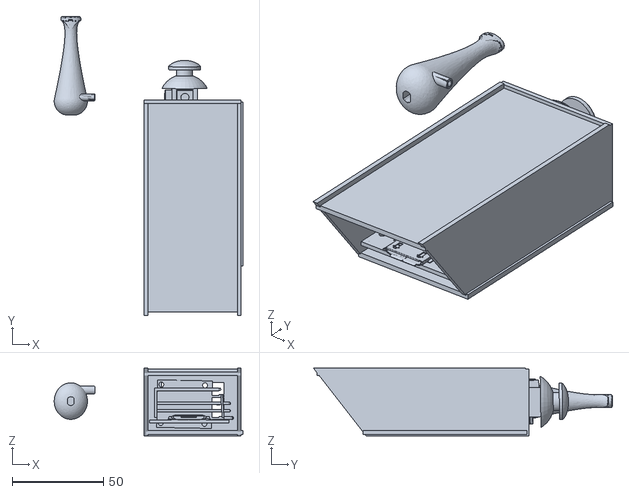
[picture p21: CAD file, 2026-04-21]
3dmodels/Modelo3d_projeto.stl
103.3 x 163.7 x 37.0

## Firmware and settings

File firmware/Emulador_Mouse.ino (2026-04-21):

#include <Mouse.h>

// --- CONFIGURAÇÕES E PINOS ---
const int horzPin = A0; // porta analogica horizontal do pino do joystick 
const int vertPin = A2; // porta analogia vertical do pino do joystick 
const int selPin = 9;  

// --- PARÂMETROS DE CONTROLE ---                                                                        
const int DEADZONE = 15; // zona morta, ou seja, o valor mínimo que o joystick precisa para ser considerado um movimento, ideal em torno de 15
const int sensitivity = 200;                                                                      // Menor valor = mais rápido


int vertZero, horzZero; // Armazena o valor inicial de cada eixo
int vertValue, horzValue; // Armazena o valor atual analógico output de cada eixo
int mouseClickFlag = 0;



// --- SETUP ---
void setup(){
  Serial.begin(9600);
  pinMode(horzPin, INPUT);                                                                        // define os dois pinos analógicos como inputs
  pinMode(vertPin, INPUT);
  pinMode(selPin, INPUT_PULLUP);                                                                   // define o pino do botão select como input com pullup interno, ou seja, ele vai ler 1 quando o botão não for pressionado e 0 quando for pressionado
  delay(1000);                                                                                    // pequeno delay para deixar os outputs se ajeitarem 
  vertZero = analogRead(vertPin);                                                                 // pega os valores iniciais
  horzZero = analogRead(horzPin);                                                                 // Joystick deve estar em uma posição neutra enquanto estiver rodando essa parte do código 
}


// --- LOOP ---
void loop()
{
  vertValue = analogRead(vertPin) - vertZero;                                                     // Lê a posição vertical e guarda os valores
  horzValue = analogRead(horzPin) - horzZero;                                                     // Lê a posição horizontal e guarda os valores
 

  Serial.print("x ");
  Serial.println(horzValue);
  Serial.print("y ");
  Serial.println(vertValue);

  if (abs(vertValue) > DEADZONE)  // verifica se o eixo x tem algum movimento
    Mouse.move(0, vertValue/sensitivity, 0); //quando ele verifica que existe movimento no eixo x entao ele usa a função move que envia os parametros (y,x,quantidades de movimentos no eixo) 
  if (abs(horzValue) > DEADZONE)  // verifica se o eixo y tem algum movimento
    Mouse.move((horzValue/sensitivity) ,0, 0); //quando ele verifica que existe movimento no eixo y entao ele usa a função move que envia os parametros (y,x,quantidades de movimentos no eixo)                                                // move o mouse no eixo x 

    
  if ((digitalRead(selPin) == 0) && (!mouseClickFlag))                                            // se o botão do joystick é pressioando
  {
    mouseClickFlag = 1;
    Mouse.press(MOUSE_LEFT);                                                                      // clica o botão esquerdo
  }
  else if ((digitalRead(selPin))&&(mouseClickFlag))                                               // Se o botão do joystick não é pressioando 
  {
    mouseClickFlag = 0;
    Mouse.release(MOUSE_LEFT);                                                                    // deixa o botão esquerdo livre
  }
}

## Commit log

2026-04-21 Add 3D model (Modelo 3d TCC.stl)
    Add binary STL file at 3dmodels/Modelo 3d TCC.stl. This commit introduces the CAD/mesh asset for the TCC project (for visualization or 3D printing).
    [Modelo 3d TCC.stl]
2026-04-21 Add joystick-based USB mouse emulator
    Add firmware/Emulador_Mouse.ino: an Arduino sketch that reads a joystick (A0 horizontal, A2 vertical) and a select button (pin 9) to emulate a USB mouse via Mouse.h.
2026-04-21 Add hardware diagrams and Fritzing project
    Add hardware assets to the hardware/ directory: Diagrama_de_Circuitos.JPG, Joystick and arduino.fzz (Fritzing project), esquema_de_funcionamento.png, and esquematico_prototipo.JPG. These files docume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
    [Joystick and arduino.fzz]
2026-04-21 Add prototype photos
    Add photos for the prototype documentation: wiring shots (Ligacoes_1/2/3), Arduino Pro Micro, dental impressions (impressao_bucal_1/2), and assembled prototype images (protitpo_finalizado_sem_involto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
2026-04-21 Add documentation PDFs and actors diagram
    Add three docs to docs/: 'Ata de Defesa Final do Trabalho de Conclusão de Curso' (defense minutes PDF), 'Relatório de Trabalho de Conclusao de curso' (final report PDF), and 'Atores_do_Sistema.jpg' (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
2026-04-21 Refactor mouse firmware and rename files
    Improve firmware readability and behavior for the joystick-based mouse emulator: make analog pin variables const, introduce a DEADZONE constant and use abs() to ignore small jitter, enable INPUT_PULLUP for the select button, and tidy comments/formatting. Rename files to remove spaces: 3dmodels/Modelo 3d TCC.stl -> 3dmodels/Modelo3d_projeto.stl and hardware/Joystick and arduino.fzz -> hardware/Joystick_and_arduino.fzz. Update .gitignore by removing the *.gcode entry and trimming extra blank lines.
    [Joystick_and_arduino.fzz, Modelo3d_projeto.stl]
2026-04-21 Add joystick prototype image
    Add new image file fotos_prototipo/joystick.jpg to include a photo of the joystick prototype for documentation and project assets.
